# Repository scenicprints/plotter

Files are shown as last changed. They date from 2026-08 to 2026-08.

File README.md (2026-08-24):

# Plotter

A Creality CR-6 SE converted into a pen plotter, plus the Windows app that
drives it. Both halves of the project live here.

Read **[HANDOFF.md](HANDOFF.md)** first. It carries the machine's hard rules
(the Z rule, the three sends, the gotchas that cost real time) and the current
tuned values.

## Layout

| Path | What |
|---|---|
| `app/` | **Plotter** — the Windows control app. Electron, one portable `.exe`, no Python, no vpype. Talks to plain Klipper + Moonraker, so it works against any Klipper plotter. See [app/README.md](app/README.md). |
| `machine/` | The machine side. `printer.cfg`, `macros.cfg`, the toolhead holder, firmware, the Pi-side tool scripts, and plotted art. |
| `docs/` | The original phase-by-phase build guide, and the early UI concept the app grew out of. |

### `machine/`

| Path | What |
|---|---|
| `printer.cfg`, `macros.cfg` | Klipper config. `macros.cfg` holds `_PLOT_VARS`, `PEN_UP` / `PEN_DOWN`, `PLOT_ZERO_HERE`, `PLOT_END`. |
| `holder.scad`, `stl/` | The owner-built pen toolhead. LM8UU bearings on 8 mm rods, gravity loaded, no spring. Pen force is carriage mass. |
| `firmware/plot001.bin` | Klipper build for the Creality v4.5.2 board. STM32F103, 28 KiB bootloader, USART1. |
| `tools/` | The earlier Pi-side pipeline: `plot`, `genart`, `mkpulsar`, `mkcard`, `mkcalib`, built on vpype. The app replaced these for day to day use. They still work and are untouched. |
| `art/`, `renders/` | Plotted SVGs and their previews. |
| `NOTES.md` | Build-time hardware notes, pin map, Klipper build target. |

## The machine

- Creality CR-6 SE, v4.5.2 board flashed with Klipper. Stock touchscreen is dead
  by design.
- Pi 4 at `plotter.local` runs Klipper, Moonraker on 7125, Mainsail on 80.
- Toolhead is owner-built and gravity loaded. To change line weight, add or
  remove mass. Never drive Z lower.
- **Z0 is the writing height and the absolute floor.** `position_min: 0`, and
  there is no Z endstop. The reference is set by hand every session and lives
  only in motion state, so a restart wipes it.

## The app

Three sends, in order, each its own card carrying only its own controls:

1. **Writing height** — Z jog, pen up/down, one click locks Z0.
2. **Card position** — XY jog pad, Z jog, card size, one click sets the origin.
3. **Plot** — pick an SVG or a line drawing, add a message, preview, send.

Everything runs in-process: SVG parsing, curve flattening, transforms,
linemerge, linesort, reloop, simplify, filter, layout, gcode. It also traces
PNG and JPG line art itself, splitting ink by thickness so thin strokes get
their centreline and solid shapes get an outline plus a hatch.

### Building it

    cd app
    npm install
    npm test
    npm run dist        # -> app/dist/Plotter.exe

`app/dist/` and `app/node_modules/` are not tracked.

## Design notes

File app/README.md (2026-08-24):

# Plotter

Windows control app for the CR-6 SE pen plotter. One portable `.exe`, no Python,
no vpype, no dependencies on the machine side. It talks to plain Klipper +
Moonraker, so it works against any Klipper plotter, not just this one.

    dist\Plotter.exe

## What it does

The three sends, in order, each as its own card carrying only its own controls:

1. **Writing height** — Z jog, pen up/down, then one click locks Z0.
2. **Card position** — XY jog pad, Z jog, card size, one click sets the origin.
3. **Plot** — pick an SVG or a line drawing, add a message, preview it, send it.

Plus jog, homing, pen test, live progress, pause, cancel, emergency stop, a
machine console, and a preview showing draw versus travel with a time estimate.

### Setting the origin

**Pen is at** takes any of the four corners or **the centre**. Corner mode adds
half the measured size to reach the sheet centre; centre mode reads the origin
straight off the pen and the measured size only records the sheet dimensions,
so it carries no sighting error at all.

Both modes need Z, because placing the pen accurately means lowering it until
it nearly touches. Step 2 therefore carries its own Z jog with its own step,
separate from step 1's fine steps.

Homing clears the gcode offset but leaves the paper size behind. The app treats
an origin of exactly 0,0 as "not set", because the sheet centre can never
legitimately be the machine origin. Without that, step 2 showed a green tick
over an origin that was gone.

## Drawings, not just SVGs

Drop a PNG or JPEG of line art and it is traced to paths on the spot. Electron
decodes the image itself, so this adds no dependency. The trace controls only
appear for a raster; an SVG never sees them.

Two treatments, picked per pixel by how thick the ink is:

- **Thin strokes get their centreline.** The skeleton of a 2px line is the
  line, so the pen draws it once instead of once down each side.
- **Solid shapes get an outline and a hatch.** Thinning a filled shape does
  not give you its middle, it gives you a ragged spine with spurs. Eyebrows,
  eyelashes, pupils and lips all fail that way, and a face traced without
  this has scribbles where its eyes should be.

**Fill over mm** is the line between the two, in millimetres of finished plot.
Anything inked thicker than that is a shape; anything thinner is a line. A blob
is only promoted if its *core* survives erosion, because a line that merely
thickens for a few pixels grows into a respectable-looking blob and would
otherwise plot as a stray black dash.

Three more things that matter:

- **Tolerances are in millimetres of paper**, converted against the image's own
  resolution, so re-exporting the same drawing at a different size does not
  change the result.
- **The image is upsampled 2x before thinning.** A 2px line has nowhere to put
  a middle; at 4px the skeleton lands where it should.
- **Smoothing happens against the pixel grid, inside the tracer.** A skeleton
  follows whole pixels, so a gently sloping line arrives as a staircase. The
  Simplify setting is in mm and is meant for real curves in real SVGs; at
  raster scale it is far too fine to flatten that, so the tracer does it.

**Save traced SVG** writes the drawing out as reusable artwork, cleaned with
the same tolerances the plot used.

**Blank an area** drags a rectangle over the preview and erases that part of
the image before tracing. It exists for artwork with lettering already rendered
into it: see below for why that has to go.

## Writing on it

Type a message and it is drawn in a **single-stroke font**, where each letter is
the path the pen travels rather than an outline to be filled. A normal font's
`o` is two closed curves, so a pen draws a hollow ring and at card sizes the
two sides of a stem smear together. These draw one line down the middle.

Eighteen fonts ship with the app in `src/fonts` (Hershey and the EMS set, taken
from Inkscape's Hershey Text extension), so nothing needs installing.

Text works **with artwork or on its own** — a card that is only a message is a
perfectly good plot.

Size is **cap height in millimetres**, measured off the font's own `H` rather
than its metadata, which several of these files get wrong. That means 5 mm
looks the same whichever font you pick.

Text is composed in paper space **after** the artwork is fitted, so 5 mm means
5 mm on the card. Folding it in before the fit would let a scale of 0.87
silently turn it into 4.35 mm, and the point of the setting is that you can
measure the result. Position is in millimetres from the sheet centre.

**If the artwork already has type in it, blank it out first.** Rendered type
traces into broken letters: thinning a filled letterform eats the dots on the
i's and the descenders on the y's, and you get "Happ, 6th Birthda,!". There is
no fixing that in the trace, because the input is an outline and the tracer is
looking for a skeleton. Erase it and set the words again.

Tracing a big drawing takes a second or two, so the result is cached against
everything that actually changes it. Feeds and dry run do not re-trace.

## The SVG pipeline is in-process

`src/core/` reimplements what `plot` + vpype did on the Pi:

| File | Does |
|---|---|
| `xml.js` | minimal XML reader |
| `svgpath.js` | path `d` parser, all commands, adaptive curve flattening, arcs |
| `svgdoc.js` | shapes, transforms, units, viewBox, layers -> polylines in mm |
| `trace.js` | raster -> paths: threshold, fill split, thinning, hatch |
| `strokefont.js` | SVG stroke fonts -> typeset paths in mm |
| `geom.js` | simplify, merge, spatial-grid nearest neighbour, sort, reloop |
| `pipeline.js` | fit, auto-rotate, order, gcode, time estimate |

A trace enters `pipeline.buildLayers` as one layer of polylines rather than
being serialised to SVG and parsed straight back. It arrives as raw skeleton
fragments — fifty thousand of them for a portrait — because `simplify`,
`merge` and `filterMin` are already exactly the clean-up a trace needs. That
is also why a trace is a single layer: layers exist for pen changes, and a
traced drawing is one pen's work.

`node test-geom.js` runs 35 correctness tests (circle perimeter, arc flags,
S/T continuation, transform composition, unit conversion, layer order).
`node test-trace.js` runs 40 over the tracer on synthetic rasters (thinning,
erosion, fill detection, scale independence, SVG round trip, huge-input safety).
`node test-text.js` runs 39 over the fonts and typesetting (every glyph present,
o really is one stroke, cap-height sizing, alignment, composition onto a plot).
`node test-core.js` runs the real artwork through end to end.
`node test-live.js` reads the actual machine, read-only.
`node_modules\.bin\electron test-trace-live.js <image>` traces a real file and
prints what the Plot card would show. It needs Electron for image decoding.

Two things that had to be right and are easy to get wrong:

- **Curve tolerance is transformed into each element's own coordinate system.**
  Flattening happens in local user units, so a viewBox scale would otherwise
  multiply the real-world error silently.
- **`<polygon>` is read and kept closed.** vpype writes closed paths as
  `<polygon>` and cannot read them back, which loses closed geometry on any
  round trip. There is no round trip here, and the reader handles it anyway.

## Machine rules it enforces

All of these came from something that actually went wrong:

- Z0 is the writing height **and** the floor. Setting a *new*, lower height
  means releasing the old reference first, so "Unlock Z0 to go lower" does the
  clear and the re-declare in one press rather than leaving a dead button and
  an error that names neither step. Nothing commands Z below it, and
  Klipper's own `position_min: 0` is the backstop. A refused move is explained
  rather than shown as a raw error.
- Positions are read only after `M400`. Straight after `G28` the second homing
  pass is still running and the number is wrong.
- After homing, X/Y park off the plate, so it moves back over the bed itself.
- Preflight before every send: Klipper ready, X/Y homed, Z referenced, Z0 set,
  paper size set, not already printing.
- **The sheet the gcode was laid out for must match the sheet the machine is
  set to**, or the send is refused. This is the error that ruined a card.
- Cancel lifts the pen but never drops the motors, so the Z reference survives.
- The generated gcode does **not** call `PLOT_END`. Loaded copies of that macro
  have run `M84`, which erases the hand-set Z reference, and its park move
  overran the rail. It ends with `PEN_UP` and a plain lift instead.
- Lift and feeds are read live off `_PLOT_VARS` at connect, never hardcoded, so
  the estimate matches the machine rather than a stale config on the laptop.

## Restart recovery

A Klipper restart wipes the origin, the paper size and the Z reference. The app
remembers the last corner and offers it back in a banner. Restoring the corner
is safe on its own: it only sets numbers, and the machine re-homes to the same
physical place. **The writing height still has to be set by hand**, because it
is a physical position with no endstop behind it.

## Dry run

On by default. Traces the whole plot in the air at Z20, clear of the hold-down
magnets, drawing nothing, so placement can be checked before committing ink.
It emits no `PEN_DOWN` at all, which is why it finishes in a fraction of the
time: the cake card is 1m 57s dry against 14m 24s real.

## Time model, and how to actually go faster

Plot time is dominated by pen lifts, not drawing. Each path costs
`lift/z_up_feed + lift/z_down_feed`: almost exactly 1.0 s at the machine's lift
of 10 mm with feeds 1800/900, read live off `_PLOT_VARS` at connect. Note that
the `macros.cfg` checked into `~/plotter` currently says lift 2.0 and 900/600,
which the machine does **not** agree with; the live values are the ones above,
and lift has to clear the carriage compression or the pen never leaves the paper.

**Merge is the lever, and it is a big one.** It joins paths whose ends nearly
touch, and every join removed is a lift saved. Measured on a 1228x1281 traced
portrait:

| Merge mm | Paths | Extra ink | Estimate | vs 0.1 |
|---|---|---|---|---|
| 0.1 | 1977 | +2% | 36m 26s | -- |
| 0.25 | 1332 | +8% | 25m 50s | -29% |
| **0.5** | **1034** | **+10%** | **20m 56s** | **-43%** |
| 1.0 | 548 | +17% | 12m 58s | -64% |
| 2.0 | 248 | +25% | 8m 11s | -78% |

**0.5 is free**: side by side with 0.1 the drawing is indistinguishable, and it
is 43% quicker. Past that you are paying in ink, because merging draws
*through* the gap rather than lifting over it. At 1.0 a stippled beard starts
joining into zigzags; at 2.0 it is a mesh and the teeth are gone. Fine detail
is what breaks first, so a portrait wants 0.5 where a bold line drawing will
happily take 2.

Raising **Min path** helps far less: it only removes ink you wanted.

Ordering is not worth optimising. Travel is around 3 m at 9000 mm/min, some
20 seconds of a twenty-minute plot, so a better tour than greedy
nearest-neighbour would win seconds.

A direction-aware merge, which only joins when the stroke genuinely carries on,
was built and measured and then removed: at matched ink it produced *more*
paths than the plain nearest-first merge, because the free zero-length joins at
skeleton junctions have mismatched directions and the angle test refused them,
reaching for distant collinear ends instead. Plain merge at a lower tolerance
beats it on both axes.

## Development

    npm start          # run from source
    npm test           # geometry + pipeline tests
    npm run dist       # build dist\Plotter.exe

`PLOTTER_SMOKE=1 PLOTTER_SMOKE_OUT=x.png npm start` boots, screenshots and
quits, for checking the UI without leaving a window open.
`PLOTTER_USERDATA=<dir>` points the saved state somewhere disposable.

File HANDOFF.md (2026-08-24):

# CR-6 SE Pen Plotter — Handoff

**The plotter works.** Read this before touching anything.

Original build guide: `docs/cr6se-plotter-build-guide.md`
(phases 0–12). Phases 1–4 and 9 are done. Owner does physical work; you do
software over SSH.

---

## Connecting

- Pi: `plotter.local` or `192.168.1.239`, user `jkevin`, SSH by key from the
  owner's laptop. Passwordless sudo.
- Mainsail: `http://plotter.local` · Moonraker API: port 7125
- Config in git at `~/plotter/` (printer.cfg, macros.cfg, tools/, art/)
- mDNS drops out occasionally — fall back to the IP.

## Hardware

- Creality **v4.5.2** board flashed with Klipper (`~/plotter/firmware/plot001.bin`,
  STM32F103, 28 KiB bootloader, USART1). Stock touchscreen is dead by design.
- Toolhead is **owner-built**: LM8UU bearings on 8 mm smooth rods,
  **gravity loaded — no spring, no rubber band** (both were tried, abandoned).
  Pen force = carriage mass. To change line weight, add or remove mass.
  Never try to increase pressure by driving Z lower — it cannot go lower.
- Carriage float: **15.9 mm** (owner measured 0.6278 in).

---

## THE Z RULE — non-negotiable

**Z0 IS the writing height AND the absolute floor.** `stepper_z position_min: 0`,
so Klipper itself rejects any move below it (verified: `G1 Z-1` returns
"Move out of range"). `PEN_DOWN` goes to Z0 and no further.

There is no Z endstop. The reference is set **by hand** every time and lives
only in motion state.

---

## The workflow — THREE SENDS

The owner confirmed this model and wants it preserved:

1. **Z height** — jog down until the pen writes with the carriage floating,
   then `PLOT_ZERO_HERE`
2. **Corner** — put the pen on the **bottom-left** corner of the card, then set
   the origin from that corner plus the card's measured dimensions
3. **Plot** — generate, upload, start

Steps 1 and 2 need the pen physically positioned, so they cannot be batched.
Step 3 is one action. Once set, further plots are a single action.

### Setting the origin from ONE corner (USE THIS)

Two-corner sighting (`PLOT_P1`/`PLOT_P2`) is still available but **one corner
plus the owner's measured dimensions is better and is what finally worked**:
it removes a whole sighting error and takes the size from a ruler rather than
from two eyeballed points.

With the pen on the bottom-left corner at machine (x, y) and card W x H:

    centre = (x + W/2, y + H/2)
    SET_GCODE_OFFSET X=<cx> Y=<cy>
    SET_GCODE_VARIABLE MACRO=_PLOT_VARS VARIABLE=paper_w VALUE=<W>
    SET_GCODE_VARIABLE MACRO=_PLOT_VARS VARIABLE=paper_h VALUE=<H>

Worked example: corner X23 Y59, card 150x100 -> centre X98 Y109. Perfect plot.

---

## Gotchas that cost real time today

- **Lift must exceed the carriage compression.** At the writing height the
  carriage is pushed up off its stop. If `lift` is smaller than that
  compression the pen never leaves the paper and every travel move draws —
  the output is scribbles. 2 mm was not enough; **10 mm works**. Default is
  now 10 in macros.cfg.
- **A restart wipes homing AND the Z reference AND the origin AND paper size.**
  Everything except what is in the config files. After any restart: re-home,
  re-set the corner, re-set Z.
- **Never restart Klipper while the machine is in a hand-set state.** Prefer
  `SET_GCODE_VARIABLE` over config edits mid-session. This ruined the owner's
  setup more than once.
- **`idle_timeout` used to run M84 after 10 min**, silently destroying the Z
  reference. Fixed: `timeout: 86400` and a gcode that does NOT drop motors.
- **`PLOT_END` used to call M84** — same problem after every finished plot.
  Removed. Its park move also overran the rail because it ignored the active
  gcode offset; now offset-aware.
- **Pen macros must check `"z" in printer.toolhead.homed_axes`**, not just an
  internal flag. A flag alone once said "zeroed" while Klipper had unhomed,
  and a job started and slammed the carriage into the bed.
- **Don't read a position immediately after `G28`.** The second homing pass is
  still running and you will read a wrong number. Cost two false alarms.
- **After homing, X/Y park at -5,-2 which is OFF the plate.** Move back over
  the bed before doing anything.
- **vpype writes closed paths as `<polygon>` and cannot read `<polygon>` back.**
  Any round-trip through an intermediate SVG silently loses closed geometry.
  Do all processing in ONE pipeline.
- **vpype `layout` enforces portrait** unless `--landscape` is passed. Without
  it a landscape sheet is laid out portrait and the centring is off by half
  the difference.
- **Writing tool files from Windows introduces CRLF** and breaks the shebang.
  Always normalise to LF before scp.
- **SVG layers are drawn in order** (layer 1, then layer 2). The owner's card
  art has `art` and `text` layers, so the text plots last. A late position
  error therefore looks like "only the text moved".

## UNRESOLVED

One card was ruined: the text landed on top of the cake. Suspected skipped
steps from `max_accel` 500 -> 2500, and the acceleration was reverted — **but
the final perfect card also ran at 2500**, so acceleration is probably NOT the
cause. The more likely explanation is an origin/corner error, since that
attempt used two-corner sighting and the successful one used the single-corner
method. Treat as unexplained. If it recurs, drop `max_accel` to 500 first.

**Z at 30 mm/s is proven, not open.** The perfect card ran 529 pen lifts, every
one at `z_up_feed` 1800 = 30 mm/s. Skipped steps would have drifted the writing
height over 529 cycles and the line would have faded out or dug in partway
through. It did not. That is a far more demanding test than a 25-cycle macro.

`ZSPEEDTEST N=25` is loaded and has never been run. It is now only worth
running if the speed is pushed **above** 30.

---

## Current tuned values

| Setting | Value | Notes |
|---|---|---|
| `max_accel` | 2500 | raised from 500; produced a perfect plot |
| `square_corner_velocity` | 8 | |
| `max_z_velocity` | 30 | raised from 15; proven over 529 lifts on the good card |
| `lift` | 10 mm | must exceed carriage compression |
| | | **`macros.cfg` in this repo says 2.0 and is STALE** — the machine reports 10 |
| `z_up_feed` / `z_down_feed` | 1800 / 900 | down is slower on purpose: no spring to absorb landing |
| `idle_timeout` | 86400 | must never drop motors |

**Plot time is dominated by pen lifts, not drawing.** At lift 10 mm each path
costs ~1.0 s. A 527-path drawing is ~8m47s of lifting and under a minute of
drawing. To speed up: fewer paths (`--filter-min`), or a smaller lift.

---

## Tools on the Pi (`machine/tools/` here, `~/plotter/tools/` on the Pi, all on PATH)

- **`plot`** — SVG to plotted. Layout, optimise, filter, gcode, preview,
  time estimate, upload. Origin is the paper CENTRE. Dry run is the default
  and flies at Z20 to clear magnets. Key flags: `--size WxH`, `-m` margin,
  `--pen`, `--filter-min`, `--dry-z`, `--keep-layers`, `--go`.
- **`genart`** — flow / spiral / moire / lissajous generative art.
- **`mkpulsar`** — ridgeline plot with hidden-line removal.
- **`mkcard`** — greeting card, auto-sized Hershey text plus a cake.
- **`mkcalib`** — Phase 10 calibration sheet.

vpype 1.15 with gwrite, hatched, vectrace, flow_img. Hershey `text` is built
into vpype core — no plugin needed.

**SVG artwork must be line art**: stroked paths, `fill="none"`. A filled SVG
plots as the OUTLINE of the filled regions (coloring-book look) and produces
hundreds of tiny contours, each costing a pen lift.

Raster artwork is a different matter: since 2026-08-23 the app traces PNG/JPG
itself and handles solid shapes deliberately, so this restriction does not
apply to images. See below.

---

## The Windows app is BUILT

`app/dist/Plotter.exe` - one portable file, 89 MB,
no install, no Python. Source and full notes in `app/README.md`.
Electron, matching MZ Forge and Anvil.

It replaces `plot` + vpype entirely for day to day use. The Pi stays plain
Klipper + Moonraker; the app does SVG parsing, curve flattening, transforms,
linemerge, linesort, reloop, simplify, filter, layout and gcode in-process.
The Pi tools still work and are untouched.

The three sends are the UI: three cards, each carrying only its own controls
(Z jog inside step 1, the XY pad inside step 2). Dry run is ON by default.

### It traces drawings too (2026-08-23)

Drop a PNG or JPG of line art in step 3 and it becomes paths in-process. No
Inkscape, no potrace, no autotrace: Electron decodes the image itself.

Ink is split by thickness and the two halves are treated differently:

- **Thin strokes get their centreline**, so the pen draws each line once
  instead of once down each side.
- **Solid shapes get an outline plus a hatch.** Thinning a filled shape does
  not give its middle, it gives a spiky spine. Eyebrows, eyelashes, pupils and
  lips all fail that way, and a face traced without this has scribbles for
  eyes. "Fill over mm" is the dividing line.

Everything lands on **one layer** — layers are for pen changes and a traced
drawing is one pen's work. "Save traced SVG" writes it out as reusable artwork.

### And it writes (2026-08-23)

Type a message and it is drawn in a **single-stroke font**: each letter is the
path the pen travels, not an outline. Plotting a normal font draws hollow
balloon letters. Eighteen fonts ship inside the app, nothing to install.

Size is cap height in mm, and text is composed AFTER the artwork is fitted, so
5 mm means 5 mm on the card whatever the art was scaled by. Works with artwork
or alone.

**If the artwork already has type rendered into it, blank that area first**
("Blank an area", drag on the preview). Rendered type traces into broken
letters and no setting fixes it.

### Going faster

Pen lifts dominate, ~1.0 s each at the live lift 10 / feeds 1800/900.
**Merge mm is the lever.** Measured on a traced portrait: 0.1 mm gives 1977
paths / 36m 26s, 0.5 gives 1034 / 20m 56s, 1.0 gives 548 / 12m 58s, 2.0 gives
248 / 8m 11s.

**0.5 is free** — indistinguishable from 0.1 by eye, and 43% quicker. Beyond
that merging draws THROUGH gaps: at 1.0 a stippled beard joins into zigzags, at
2.0 the teeth are gone. Fine detail breaks first, so a portrait wants 0.5 and a
bold line drawing will take 2. Travel ordering is not worth touching; it is
~20 s of a twenty-minute plot.

Verified against the live machine on 2026-08-23: read-only status parse,
35 geometry, 40 tracer and 39 text tests, the cake card end to end (747 paths,
14m 24s real / 1m 57s dry), a 1228x1281 wedding portrait traced to 1995 strokes
and 10.29 m of draw in about a second, and the packaged .exe booting,
connecting and tracing.

### What it refuses to do, and why

- Send when the sheet the gcode was laid out for does not match the sheet the
  machine is set to. **This is the error that ruined the card.**
- Send at all unless preflight passes: Klipper ready, X/Y homed, Z referenced,
  Z0 set, paper size set, nothing already printing.
- Drop the motors on cancel. It lifts the pen and leaves them on, so the Z
  reference survives.
- Call `PLOT_END`. Loaded copies of that macro have run `M84`. It emits
  `PEN_UP` + a plain lift instead, the same known-good ending `plotter.toml`
  uses.

### Still by hand

The writing height. It is a physical position with no endstop, so after a
restart the app can restore the corner and the card size from memory but the
Z reference has to be re-set by jogging. The app says so in the banner.

### Note on the local config copies

`macros.cfg` in this folder is STALE against the Pi: it still says lift 2.0,
feeds 900/600, and a `PLOT_END` that calls `M84`. The live machine has lift 10
and feeds 1800/900. The app reads `_PLOT_VARS` off the machine at connect
rather than trusting any local file. Worth pulling the Pi's copy back down
into this repo.

## ALSO PLANNED: hotspot fallback

The owner wants to take the Pi and plotter to places where devices cannot see
each other and IPs change (e.g. work). Plan: NetworkManager AP profile with
lower autoconnect priority than the home network, so it joins `coronawireless`
at home and otherwise broadcasts its own network at a fixed address.

**This is the change most likely to lose SSH access to the Pi.** Do it with a
revert timer, and not while a plot is running.

Also worth doing: a DHCP reservation for the Pi on the owner's UDM Pro.

---

## Working with this owner

- He is hands-on and fast. Give the value, not the reasoning.
- **Never start a plot unless he has clearly asked for it in that moment.**
  Starting one on an assumption wasted a real card and his time.
- Ask before physical actions that could damage something, but do not stack up
  questions — he gets frustrated with repeated confirmation.
- When he corrects you, fix it and move on. Do not explain at length, and do
  not shift blame onto him — his corners were right when I suggested otherwise.
- Verify with a command rather than assuming; several bugs today were only
  caught by actually running the thing.

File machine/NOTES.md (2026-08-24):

# CR-6 SE Pen Plotter - staging repo

Files here are staged on the Windows laptop and copied to the Pi (`~/plotter/`)
once it is reachable. Guide: `docs/cr6se-plotter-build-guide.md`

## Hardware facts established

- Mainboard: **Creality v4.5.2**
- Klipper build target (from upstream `config/printer-creality-cr6se-2020.cfg`):
  - STM32F103
  - **28 KiB bootloader**
  - Communication: **serial on USART1 (PA10/PA9)**, reached over the board's USB
- Pi 4, hostname `plotter`, user `jkevin`

## Pin map, stock -> plotter

| Pin  | Stock use | Plotter use |
|---|---|---|
| PA4  | strain gauge probe | unused (Option C Z-homing if ever wanted) |
| PA6  | case LED output | **servo signal candidate** |
| PA7  | filament switch in | **Z endstop candidate** (Option A) |
| PA0/PA1/PA2 | fans, hotend, bed | deleted from config |

Both PA6 and PA7 are freed by the strip, so Option A (mechanical Z switch)
and a mainboard-timed servo can coexist. Confirm physically at Phase 1.1/6.2.

## Status

- [x] Phase 1 - board identified, build target derived
- [~] Phase 2 - Pi imaged; **not yet on the network** (see below)
- [ ] Phase 3 - firmware build + flash
- [ ] Phase 4 - motion config

## Open problem: Pi will not join WiFi

The Pi boots correctly (rootfs auto-expanded 2.6 GB -> 59 GB, which only
happens on a successful boot) but ignored two headless-config formats:

1. `rpi-preseed.toml` - written per rpi-imager docs for Trixie. Ignored.
2. cloud-init `user-data` / `network-config` - files present on the image but
   apparently not processed. Ignored (no `runcmd` side effects appeared).

Current attempt: the `systemd.run=` + `firstrun.sh` mechanism taken from
rpi-imager's own source (`src/downloadthread.cpp`), which is independent of
whichever config package the image ships. It writes `/boot/firmware/firstrun.log`
and installs `plotter-diag.service` to dump full network state to
`/boot/firmware/diag/net.txt` on the following boot.

**Next diagnostic step:** read `firstrun.log` off the card. Its presence or
absence is decisive - absent means `systemd.run` never fired, present means the
script ran and the log says exactly how far it got.

Fallback if WiFi keeps failing: wired ethernet to the Pi. The configs already
accept DHCP on eth0.

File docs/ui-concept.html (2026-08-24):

Plotter 1.0

plotter.local · Ready

X 98.0 Y 109.0 Z 0.00

–▢✕

Plot Artwork Machine Settings STOP

Klipper restartedLast session: Z0 · corner X23.0 Y59.0 · card 150 × 100

Restore

✓Writing height Z0 locked

Jog down until the pen writes with the carriage floating off its stop, then lock. Z0 is the floor, it cannot go lower.

Z position4.35

Carriage float15.9

▲ +1▲ +0.1

▼ −0.1▼ −1

Step (mm)

0.05 0.1 0.5 1

Pen downPen up

Lock Z0 here

2Card corner bottom-left

Put the pen on the bottom-left corner of the card, enter the size you measured, and set the origin.

X23.0

Y59.0

Centre98 · 109

Step (mm)

0.1 1 10 50

Card preset

150×100 A6 A5 4×6″

Width mm

×

Height mm

Set origin from this corner

3Plot 9m 14s

art-cake-outline.svg

527 paths · drop a new SVG or click to browse

Margin mm

Min path mm

Pen

Dry runFlies at Z20 to clear the magnets, nothing is drawn Send plot

Preview

Draw

Travel

Fit

Paths527

Draw4.24 m

Travel2.91 m

Pen lifts527

Estimate9m 14s

Plotting34% path 179 / 527 · 6m 02s left

Pause Cancel

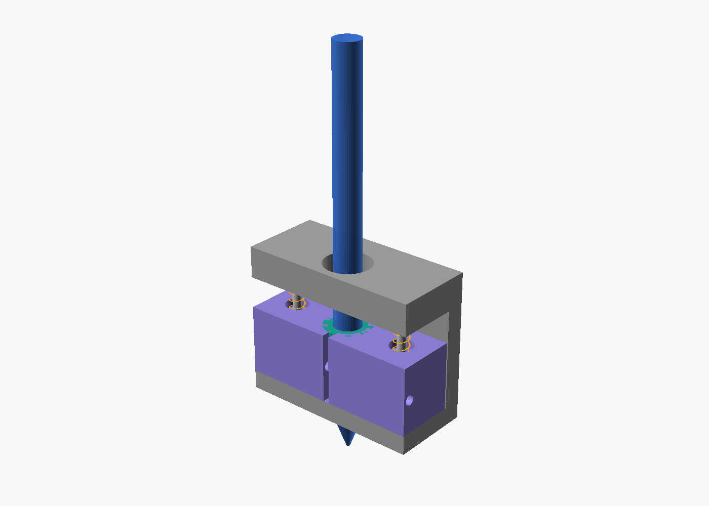
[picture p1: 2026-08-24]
machine/renders/holder-iso.png

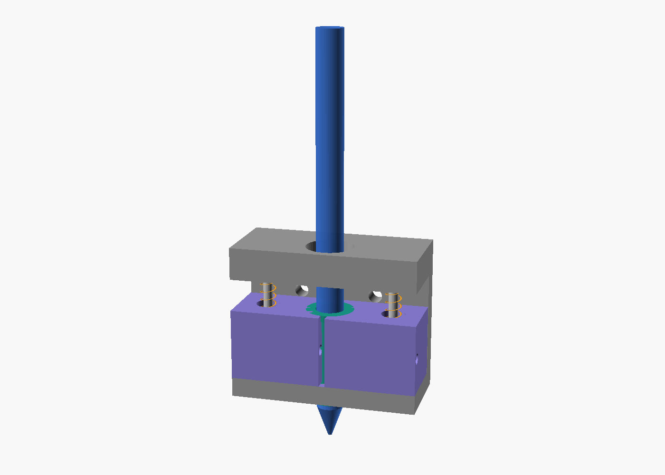
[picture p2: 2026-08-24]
machine/renders/holder-front.png

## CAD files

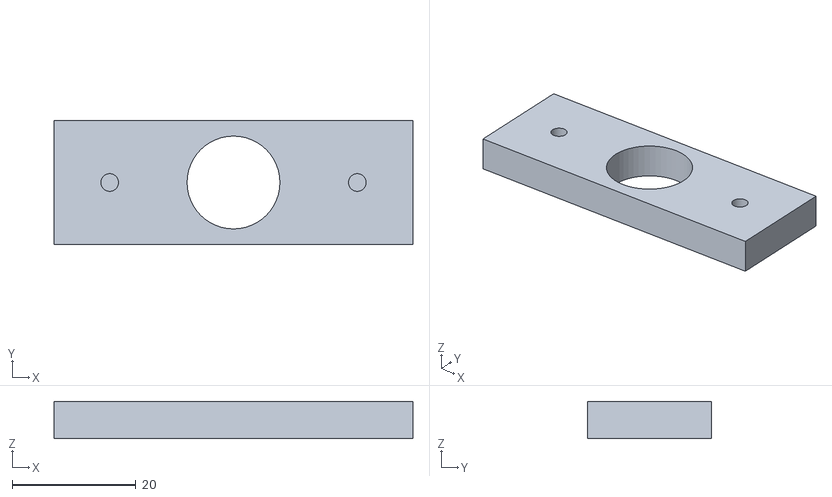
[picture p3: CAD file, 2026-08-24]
machine/stl/holder-bottom.stl
58.0 x 20.0 x 6.00

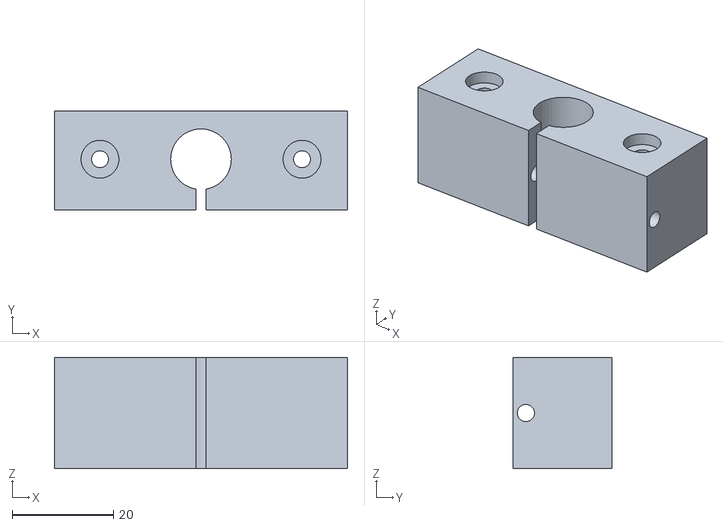
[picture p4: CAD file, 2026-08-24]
machine/stl/holder-carriage.stl
58.0 x 19.5 x 22.0

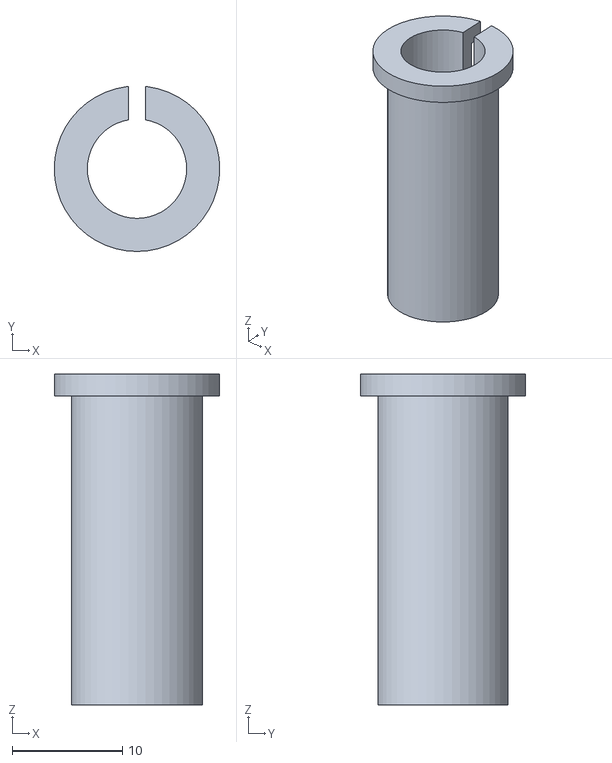
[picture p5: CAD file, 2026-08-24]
machine/stl/holder-sleeve.stl
15.0 x 15.0 x 30.0

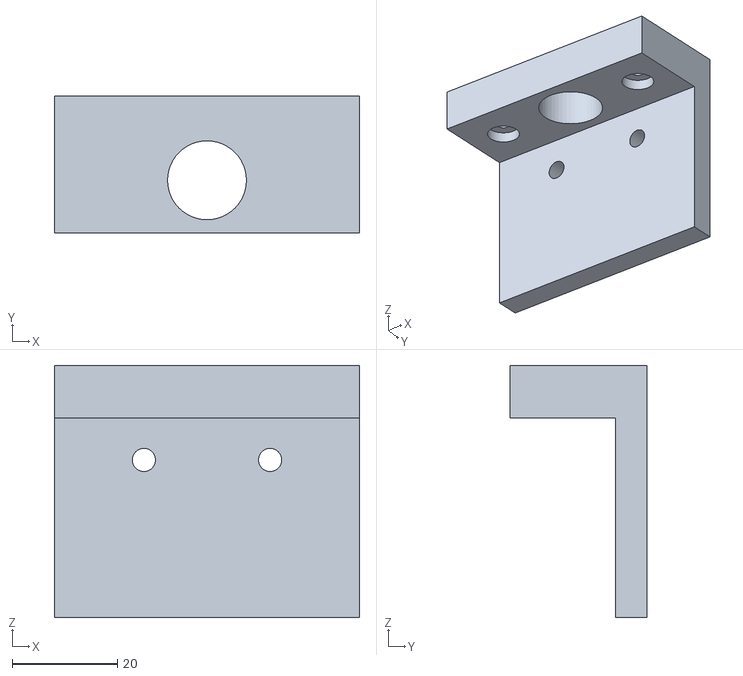
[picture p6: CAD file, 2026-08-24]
machine/stl/holder-top.stl
58.0 x 26.0 x 48.0

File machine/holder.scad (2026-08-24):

// CR-6 SE pen plotter holder, v1
// Two 3mm steel guide rods, sprung carriage, per-pen sleeves.
// Mount-plate hole spacing is a PLACEHOLDER until the bracket is measured.
// All dims in mm.

$fn = 48;

// ---------------- parameters ----------------
rod_d          = 3.0;    // steel rod diameter
rod_len        = 45;     // rod length
rod_spacing    = 40;     // centre-to-centre
rod_clear      = 0.35;   // carriage bore clearance over rod
rod_press      = 0.15;   // press-fit undersize in plates

plate_w        = 58;     // x
plate_d        = 20;     // y
top_t          = 10;     // top plate thickness
bot_t          = 6;      // bottom plate thickness

carriage_h     = 22;
sleeve_bore    = 12;     // carriage centre bore, all sleeves share this OD
pen_hole       = 15;     // pen clearance through both plates

spring_od      = 5.2;    // click-pen spring
spring_wire    = 0.45;
spring_seat_d  = 7.5;    // locating counterbore
spring_seat_dp = 2.5;

wall_t         = 6;      // back wall that meets the bracket
wall_h         = 48;
mount_hole_d   = 4.4;    // M4 clearance  (PLACEHOLDER)
mount_spacing  = 24;     // hole spacing  (PLACEHOLDER - measure bracket)
mount_z        = 30;     // hole height   (PLACEHOLDER - measure bracket)

clamp_slit     = 2.0;
clamp_hole_d   = 3.4;    // M3 clearance

// BIC Cristal sleeve
bic_barrel     = 9.0;    // hex barrel across corners ~8.9
sleeve_len     = 30;
flange_d       = 15;
flange_t       = 2;

// derived
rx = rod_spacing/2;
carriage_z0 = bot_t;                 // carriage rests on bottom plate
top_z0 = rod_len + 1 - 8 + 0;        // top plate underside so rods socket 8mm
// keep simple: place explicitly
top_bottom = 38;                     // underside of top plate
travel = top_bottom - (carriage_z0 + carriage_h);   // = 10mm free travel

// ---------------- parts ----------------

module rod() color("silver") cylinder(d=rod_d, h=rod_len);

module spring(h) {
    color([0.95, 0.62, 0.12])
    linear_extrude(height=h, twist=-360*6, slices=120)
        translate([spring_od/2 - spring_wire/2, 0]) circle(d=spring_wire);
}

module bottom_plate() color([0.62,0.62,0.62]) difference() {
    translate([-plate_w/2, -plate_d/2, 0]) cube([plate_w, plate_d, bot_t]);
    // rod sockets (blind, press fit)
    for (s=[-1,1]) translate([s*rx, 0, 1]) cylinder(d=rod_d-rod_press, h=bot_t);
    // pen clearance
    cylinder(d=pen_hole, h=3*bot_t, center=true);
}

module top_plate() color([0.62,0.62,0.62]) difference() {
    union() {
        translate([-plate_w/2, -plate_d/2, top_bottom]) cube([plate_w, plate_d, top_t]);
        // back wall down to bottom, meets the bracket face
        translate([-plate_w/2, plate_d/2, 0]) cube([plate_w, wall_t, wall_h]);
    }
    // rod sockets, blind from below
    for (s=[-1,1]) translate([s*rx, 0, top_bottom]) cylinder(d=rod_d-rod_press, h=8);
    // pen clearance
    translate([0,0,top_bottom-1]) cylinder(d=pen_hole, h=top_t+2);
    // spring locating counterbores on the underside
    for (s=[-1,1]) translate([s*rx, 0, top_bottom-0.01]) cylinder(d=spring_seat_d, h=spring_seat_dp);
    // bracket mount holes (PLACEHOLDER spacing)
    for (s=[-1,1]) translate([s*mount_spacing/2, plate_d/2-1, mount_z])
        rotate([-90,0,0]) cylinder(d=mount_hole_d, h=wall_t+2);
}

module carriage() color([0.55,0.50,0.85]) difference() {
    translate([-plate_w/2, -plate_d/2, carriage_z0]) cube([plate_w, plate_d-0.5, carriage_h]);
    // rod bores
    for (s=[-1,1]) translate([s*rx, 0, carriage_z0-1]) cylinder(d=rod_d+rod_clear, h=carriage_h+2);
    // spring seats on top face
    for (s=[-1,1]) translate([s*rx, 0, carriage_z0+carriage_h-spring_seat_dp]) cylinder(d=spring_seat_d, h=spring_seat_dp+1);
    // sleeve bore
    translate([0,0,carriage_z0-1]) cylinder(d=sleeve_bore, h=carriage_h+2);
    // clamp slit, front face to bore
    translate([-clamp_slit/2, -plate_d/2-1, carriage_z0-1]) cube([clamp_slit, plate_d/2+1, carriage_h+2]);
    // M3 clamp screw crossing the slit
    translate([-plate_w/2-1, -7.5, carriage_z0+carriage_h/2]) rotate([0,90,0]) cylinder(d=clamp_hole_d, h=plate_w+2);
}

module sleeve() color([0.10,0.62,0.55]) difference() {
    union() {
        cylinder(d=sleeve_bore-0.15, h=sleeve_len);
        translate([0,0,sleeve_len-flange_t]) cylinder(d=flange_d, h=flange_t);
    }
    translate([0,0,-1]) cylinder(d=bic_barrel, h=sleeve_len+2);
    translate([-0.75, 0, -1]) cube([1.5, flange_d, sleeve_len+2]);
}

module pen_mock() color([0.22,0.45,0.85,0.85]) {
    translate([0,0,-4]) cylinder(d=8.5, h=118);
    translate([0,0,-14]) cylinder(d1=1.2, d2=8.5, h=10);
}

// ---------------- assembly ----------------
module assembly() {
    bottom_plate();
    top_plate();
    for (s=[-1,1]) translate([s*rx, 0, 1]) rod();
    carriage();
    // springs sit between carriage top and top plate underside
    for (s=[-1,1]) translate([s*rx, 0, carriage_z0+carriage_h-spring_seat_dp]) spring(top_bottom - (carriage_z0+carriage_h) + 2*spring_seat_dp);
    // sleeve in carriage, flange resting on carriage top
    translate([0,0,carriage_z0+carriage_h-sleeve_len]) sleeve();
    pen_mock();
}

part = "assembly"; // assembly | top | bottom | carriage | sleeve

if (part == "assembly") assembly();
if (part == "top")      top_plate();
if (part == "bottom")   bottom_plate();
if (part == "carriage") carriage();
if (part == "sleeve")   sleeve();

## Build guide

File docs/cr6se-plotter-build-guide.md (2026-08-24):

# CR-6 SE → Pen Plotter: Full Build Guide

A step-by-step conversion of a Creality CR-6 SE into a dedicated pen plotter running
Klipper on a Raspberry Pi. This machine will never 3D print again — that assumption
drives many of the decisions below.

**This document is written for two readers:**

- **[HUMAN]** — physical work, judgement calls, anything involving a screwdriver or eyeballs.
- **[CC]** — Claude Code, working over SSH on the Pi. Software, config, scripts, debugging.

Each phase ends with a **Done when** line. Do not move to the next phase until it's true.

---

## A note on ordering

The usual version of this build has a hard constraint: print your plastic parts before you
remove the hotend, because afterwards the machine can't make its own parts.

**That constraint does not apply here.** There are other printers available, so the pen
holder is not a one-shot design you have to get right before committing. It's an iterative
fit-and-refine loop that can run *while the CR-6 is already stripped and on the bench* —
which is strictly better, because you can measure the real bracket, test the real flex, and
reprint the same afternoon.

Phase 0 is therefore just measuring and shopping. The holder design gets its own phase
(Phase 6), positioned after the strip where it belongs.

---

## Verification policy for [CC]

Some details in this guide are version-sensitive and may have drifted. Before acting on
anything marked **[VERIFY]**, fetch current upstream documentation and reconcile. If
upstream contradicts this document, upstream wins — say so out loud rather than silently
following either one.

Primary sources:
- Klipper install & config: https://www.klipper3d.org/
- Klipper example configs: `klipper/config/` in the cloned repo
- KIAUH: https://github.com/dw-0/kiauh
- vpype: https://vpype.readthedocs.io/

---

# PHASE 0 — Print parts and buy things

## 0.1 [HUMAN] Print the parts that aren't design-sensitive

These don't interact with the toolhead, so there's nothing to iterate on. Print whenever.

| Part | Notes |
|---|---|
| Paper registration corners | L-shaped blocks, print 2–4 |
| Pi case or bed-frame mount | Optional, keeps wiring tidy |
| Cable strain relief | For the slimmed-down toolhead loom |

The pen holder and servo mount are **not** on this list. They depend on measurements you
can't take until the toolhead is bare. See Phase 6.

## 0.2 [HUMAN] Set aside a design printer

Pick whichever of the other machines has the best small-part accuracy and keep it loaded
with a filament you like. Phase 6 will ask it for four or five iterations over a day or
two, and you don't want that competing with a long print.

PETG is the better choice over PLA here — the holder sits under constant light spring
load, and PLA creeps under sustained stress over months.

## 0.3 [HUMAN] Shopping list

**Electronics**
- Raspberry Pi (any Pi 3B+ or newer; Pi Zero 2 W works but is slow to build firmware on)
- Good 5V power supply for the Pi — undervoltage causes bizarre, hard-to-diagnose faults
- microSD card for the Pi, 16 GB+
- **A second microSD card, 8 GB or smaller, for flashing the mainboard** (see 3.3)
- SG90 or MG90S 9g servo (MG90S has metal gears and is worth the extra dollar)
- Dupont jumper wires, female-to-female
- USB-A to USB-B cable (Pi → printer mainboard) — probably already have one
- *Optional:* mechanical microswitch for a Z endstop (see 4.4)

**Pens — buy in this order**

| Priority | Pen | Why |
|---|---|---|
| **Buy first** | **BIC Cristal ballpoint, box of 10** | Your calibration pen. Nearly indestructible, tolerates crashes and bad Z, costs nothing. Do all setup and testing with these. Never risk a good pen on an untuned machine. |
| **Buy first** | **Sakura Pigma Micron 05 (0.45 mm)** | The default "good" plotter pen. Pigment ink, archival, consistent line, doesn't bleed. The 05 is the sweet spot — finer tips (01, 005) fray faster and need slower speeds. |
| Add soon | **Sharpie Fine Point** | Dark, bold, cheap, bulletproof. Bleeds on cheap paper. Great for large generative work. |
| Add soon | **Uni-ball Signo / Sakura Gelly Roll, white** | For plotting on black paper, which looks fantastic and is half the reason people build these. |
| Technical work | **Staedtler Pigment Liner 308** or **Rotring Tikky Graphic** | Consistent widths in a matched set (0.1 / 0.3 / 0.5), good for drawings where line weight is semantic. |
| Later, if you get serious | **Rotring Isograph** (refillable) | Best line consistency available. Expensive, clogs if left uncapped or unused, needs actual maintenance. Not a starter pen. |

**Do not start with fineliners finer than 0.3 mm.** They fray on any paper that isn't
very smooth, and they punish Z errors that a ballpoint would shrug off.

**Paper**
- **Bristol board, smooth (not vellum) surface** — the plotter standard. Rough paper
  destroys fineliner tips.
- HP Premium32 or similar heavy smooth laser paper for cheap testing
- Black cardstock if you bought white gel pens

**Hold-down**
- Low-tack masking tape or small bulldog clips
- The printed registration corners from 0.1

**Done when:** registration corners printed, pens and paper ordered, Pi in hand, a design
printer standing by.

---

# PHASE 1 — Identify your mainboard

**Do this before downloading anything.** The CR-6 SE shipped with several different
boards across production runs, and flashing the wrong firmware is the one genuinely
risky step in this build.

## 1.1 [HUMAN] Open the base and read the silkscreen

Power off, unplug from mains, remove the bottom cover. Photograph the board. Look for:

- A version string silkscreened on the PCB (e.g. `CR-6 SE v4.5.2`, `v4.5.3`, `ERA`)
- The main MCU chip marking — read the text on the largest square chip. You're looking
  for something like `STM32F103RET6` or `GD32F303RET6`.
- Whether there are any **unused 3-pin headers** (5V / GND / signal). Photograph these
  and any labels near them. You may want one for the servo and one for a Z endstop.

Write down exactly what you see. Guessing here is how boards get bricked.

## 1.2 [CC] Determine the correct Klipper build target

**[VERIFY]** Given the board revision and MCU marking from 1.1, determine:
- Klipper `menuconfig` MCU family
- Correct **bootloader offset** (Creality 32-bit boards commonly use 28 KiB, but confirm
  for this specific revision)
- Communication interface (USB vs serial, and which pins)

Note for [CC]: some CR-6 SE boards use a **GD32F303**, which is a clone of the STM32F103.
Klipper handles this, but the correct target selection is a known gotcha. Check the
Klipper docs and the `klipper/config/` directory for a shipped CR-6 SE example config
before deciding. If you cannot establish this with confidence, **stop and say so** rather
than producing a firmware binary on a guess.

**Done when:** board revision, MCU part number, and Klipper build target are all written
down and agreed on.

---

# PHASE 2 — Raspberry Pi setup

## 2.1 [HUMAN] Flash and boot the Pi

- Raspberry Pi Imager → Raspberry Pi OS **Lite** (64-bit). No desktop needed.
- In the Imager's settings gear: set hostname (`plotter` is a good choice), enable SSH,
  set username/password, configure WiFi.
- Boot the Pi, confirm you can `ssh` in.

## 2.2 [HUMAN] Hand the Pi to Claude Code

Give [CC] SSH access. From here [CC] does the software work.

## 2.3 [CC] Install the Klipper stack

Use **KIAUH** (Klipper Installation And Update Helper) — it handles the whole stack and
its service wiring correctly.

Install, in order:
1. **Klipper**
2. **Moonraker** (the API layer — this is what lets you drive the machine programmatically)
3. **Mainsail** (web UI — the human will want this for jogging and emergency stop)

**[VERIFY]** KIAUH's repo URL and install procedure.

Set up a git repo at `~/plotter/` to version-control `printer.cfg`, macros, vpype configs,
and scripts. Commit after every working change. You will break things and want to walk back.

**Expect Mainsail to look half-broken** once you're running — empty temperature graphs, no
extruder panel. Nothing is wrong; you deleted those sections from `printer.cfg` on purpose
in Phase 4. The jog controls, console, and file manager are all you need from it. A
plotter-shaped replacement is Phase 12, deferred until you've actually used the machine.

**Done when:** Mainsail loads in a browser, `systemctl status klipper` is running (it will
report an MCU connection error — that's expected, nothing is flashed yet).

---

# PHASE 3 — Build and flash the mainboard firmware

## 3.1 [CC] Build the firmware

In `~/klipper`: run `make menuconfig` with the settings established in 1.2, then `make`.

Output lands at `~/klipper/out/klipper.bin`.

## 3.2 [CC] Prepare the binary

Copy `klipper.bin` to a **uniquely named** file — e.g. `plot001.bin`. Increment this
number on every reflash, forever.

**Why:** Creality bootloaders track the last-flashed filename and will silently skip a
file with a name it has already seen. A "failed flash" that is actually just a skipped
flash has eaten many hours.

## 3.3 [HUMAN] Flash it

- Use the **small (8 GB or under) SD card**, formatted **FAT32, 4096-byte allocation unit
  size**. Large cards and wrong cluster sizes are the #1 cause of Creality boards refusing
  to flash.
- The card should contain **only** the `plot001.bin` file. Nothing else.
- Printer **off**. Insert card. Power **on**. Wait 15–30 seconds. The screen may stay
  blank or show garbage — this is expected and fine.
- Power off, remove the SD card.

## 3.4 [HUMAN] Connect the Pi

USB cable from Pi to the printer mainboard. Power the printer on.

## 3.5 [CC] Find the MCU

Run Klipper's serial ID helper to get the `/dev/serial/by-id/...` path. Record it — it
goes in `printer.cfg`.

If nothing appears: the flash didn't take. Return to 3.2, increment the filename, and
re-check the SD card format before assuming a firmware problem.

**Expect the stock touchscreen to be dead from now on.** It's a separate MCU that doesn't
speak Klipper. This is normal and doesn't matter — you'll drive everything from Mainsail.

**Done when:** `ls /dev/serial/by-id/` shows the board.

---

# PHASE 4 — Minimal motion config

**Goal: get X, Y, and Z moving. Nothing else. Do not attach a pen yet.**

## 4.1 [CC] Write a stripped `printer.cfg`

Start from the CR-6 SE example config if Klipper ships one, then **delete**:
- `[extruder]` — entirely
- `[heater_bed]` — entirely
- `[heater_fan]`, `[fan]` — entirely
- Any `[verify_heater]`, thermistor, or thermal protection sections
- Any probe / bed mesh sections **for now** (added in Phase 7)

This deletion is the whole point of the Klipper path: MINTEMP faults, cold-extrusion
guards, and thermal runaway protection stop being things you work around because they
stop existing.

Keep and configure:

```
[mcu]                 # serial path from 3.5
[printer]             # kinematics: cartesian
[stepper_x]           # rotation_distance: 40, position_max: 235
[stepper_y]           # rotation_distance: 40, position_max: 235
[stepper_z]           # rotation_distance: 8, position_max: 250
[virtual_sdcard]
[pause_resume]
[display_status]
```

**[VERIFY]** rotation_distance values against the actual machine — CR-6 SE uses 20-tooth
GT2 pulleys (40 mm/rev) and a T8 lead screw (8 mm/rev), but confirm empirically in 4.3.

Start with **conservative** `max_velocity` / `max_accel`. Tuning comes in Phase 11.

## 4.2 [HUMAN] Test with your hand on the power switch

First `G28 X` and `G28 Y`, one axis at a time, ready to cut power if anything drives into
a hard stop.

## 4.3 [CC + HUMAN] Verify dimensional accuracy

Command a 100 mm X move. **[HUMAN]** measures actual travel with calipers or a steel rule.
Repeat for Y. Adjust `rotation_distance` proportionally if off. Get this right now — every
drawing you ever make inherits this error.

## 4.4 The Z homing problem

**The CR-6 SE has no mechanical Z endstop.** Stock, it homes Z using the strain gauge in
the toolhead bracket. We are not using the strain gauge, so Z needs a plan. Pick one:

**Option A — Mechanical switch (recommended, most bulletproof).**
Mount a microswitch to the frame so the X gantry trips it near the bottom of travel. Wire
to a free input identified in 1.1. Set as a normal `endstop_pin` in `[stepper_z]`. Set
once, correct forever, zero per-session ritual.

**Option B — Software Z reference (zero hardware, recommended if no free input).**
Skip Z homing entirely. At the start of each session:
1. Jog Z by eye until the pen is just clear of the paper
2. `SET_KINEMATIC_POSITION Z=5`
3. `G28 X Y`

Wrap this in a `PLOT_HOME` macro so it's one click. Costs you a 20-second ritual per
session. Because Z travel on a plotter is only a few millimetres, the loss of absolute Z
reference genuinely doesn't matter.

**Option C — Re-enable the strain gauge as a Z endstop only.**
The wiring already exists and the bracket is still the load cell. This is available if A
and B both annoy you, but it's the least-documented path and it's why we routed around it
in the first place.

**Done when:** all three axes move accurately and repeatably, and Z has a homing story.

---

# PHASE 5 — Strip the toolhead

Now, and not before now.

## 5.1 [HUMAN] Before you unplug anything

**Photograph every connector from multiple angles.** You will not remember which
2-pin plug went where.

**Trace the X endstop wiring first.** On some CR-6 SE units, toolhead-adjacent wiring runs
through the same loom. If you pull the loom and lose X homing, you've created a new problem.
Confirm X and Y endstops still work (`G28 X`, `G28 Y`) after every removal step.

## 5.2 [HUMAN] Remove

Power off and unplug from mains first. Remove:

- Hotend heater cartridge
- Thermistor
- Heatsink and heatbreak
- Hotend cooling fan
- Part cooling fan and duct
- Nozzle and heater block
- Extruder motor and Bowden/direct assembly
- Any plastic shroud that doesn't hold the bracket together

**Keep:**
- The **toolhead mounting bracket** — this is your pen mounting surface and it's also the
  strain-gauge load cell if you ever want Option C
- X carriage, wheels, belt, and belt tensioners
- X and Y endstops and their wiring
- All motion hardware

**Tidy the loom.** You've removed most of the wires in it. Cut it down, re-sleeve, and
strain-relieve it. Slack cable that snags mid-plot ruins the drawing.

## 5.3 [CC] Confirm nothing broke

`FIRMWARE_RESTART`, then re-run the Phase 4 tests. All three axes should behave identically
to before the strip. If Klipper now complains about a missing component, something is still
referenced in `printer.cfg` that shouldn't be.

**Done when:** the toolhead is bare, and X/Y/Z motion and homing are unchanged.

---

# PHASE 6 — Mount pen and servo

## 6.1 The pen holder design loop

Don't download someone else's holder. The CR-6 toolhead bracket isn't an Ender 3 bracket,
you have printers available, and a parametric design lets you tune the two things that
actually determine plot quality — rigidity and spring rate — instead of accepting a
stranger's guesses.

### 6.1a [HUMAN] Measure the bare bracket

With the toolhead stripped (Phase 5 complete), measure and record:

- Mounting hole spacing, X and Y, centre to centre
- Hole diameter
- Bracket face dimensions and any obstructions (screw heads, standoffs, belt clamp)
- **Distance from the bracket face to where the nozzle tip used to be**, in X, Y and Z
- Clearance behind the bracket for a servo body
- Belt path and X-carriage wheels — the holder must not foul either at full travel

Photograph with a rule in frame. Hand measurements and photos to [CC].

### 6.1b [CC] Generate a parametric OpenSCAD holder

Build `holder.scad` with everything above as named variables at the top of the file, plus:

```
pen_diameter        // barrel OD at the grip point
collet_wall         // sleeve thickness
spring_travel       // 3–5 mm
spring_od, spring_free_length
servo_arm_height    // where the lifter finger engages
tip_offset_x, tip_offset_y   // relative to old nozzle position
```

Emit both the holder body and a **collet** — a printed sleeve that adapts one pen barrel to
the holder's fixed bore.

**Design the collets so every pen's *tip* lands at the same Z when seated**, not so every
barrel seats at the same depth. Pens vary in tip-to-shoulder distance, so referencing off
the barrel means re-measuring `PEN_Z` on every swap. Referencing off the tip makes `PEN_Z`
a function of paper stock only — which is the whole point of section 7.4.

Print a collet per pen you own. This is the payoff for having spare printers: a $0 sleeve
per pen instead of a compromise clamp that half-fits everything.

### 6.1c [HUMAN + CC] Iterate

Four passes, roughly:

| Rev | Goal | What to check |
|---|---|---|
| v1 | Mount fit only — no pen bore, no spring | Bolts up flush, no rocking, clears belt and wheels at full X travel |
| v2 | Add pen bore and collet | Pen vertical in both axes (small square), no rotation, tip lands near old nozzle position |
| v3 | Add sprung travel | 3–5 mm, smooth, returns freely under its own spring, no binding |
| v4 | Add servo interface | Lifter finger engages cleanly, no side load on the carriage |

**The rigidity test that matters:** push sideways on the seated pen tip with a finger.
Any perceptible flex in the *mount* will show up as wandering lines. Compliance belongs
in the sprung travel and nowhere else. If v1 flexes, thicken it and reprint — this is a
20-minute fix now and an unfixable annoyance later.

Spring rate: a ballpoint pen's own spring is roughly right as a starting point. Too stiff
tears paper and fights the servo; too soft won't hold the pen down through direction
changes.

### 6.1d [HUMAN] Final mount

Bolt on the winning revision. Record the final `tip_offset_x` / `tip_offset_y` — these go
into the vpype profile in 9.2.

**Install a BIC Cristal.** Not a Micron. Not yet.

## 6.2 [HUMAN] Mount the servo

Mount the SG90 so its arm lifts the sprung pen carriage. Aim for roughly 4–5 mm of lift —
enough to clear the paper and any ink already laid down, not so much that lifts get slow.

Wire: signal to the free header pin from 1.1, plus 5V and GND.

**If the servo browns out or the board resets when it moves**, its stall current is too
much for the board's 5V rail. Power the servo from the Pi's 5V or a separate BEC instead,
**keeping ground common with the mainboard.** A servo on a separate supply with a floating
ground will behave erratically in ways that look like a software bug.

## 6.3 [CC] Add the servo to Klipper

```
[servo pen]
pin: <pin from 1.1>
minimum_pulse_width: 0.0005      # tune
maximum_pulse_width: 0.0025      # tune
initial_angle: <pen up angle>
```

**Use a mainboard pin, not a Pi GPIO.** Klipper schedules mainboard servo commands on the
same timeline as motion, so pen-up lands exactly where the toolpath says. A Pi GPIO servo
is outside the motion queue and will lag unpredictably — you'll get little ink tails on
every lift.

## 6.4 [CC] Find the angles, [HUMAN] eyeballs it

Iteratively `SET_SERVO SERVO=pen ANGLE=...` until you find clean up and down positions.
Record both. **Down should let the spring do the work** — the servo arm should release the
carriage, not press it into the paper.

**Done when:** `SET_SERVO` reliably lifts and drops the pen, with no board resets.

---

# PHASE 7 — Z reference and the one-time bed mesh

The bed on this machine is never coming off and never getting heated. Measure it once,
save it, never think about it again.

## 7.1 [CC] Add manual bed mesh

```
[bed_mesh]
speed: 60
horizontal_move_z: 5
mesh_min: 20, 20
mesh_max: 215, 215
probe_count: 5, 5
```

With no probe defined, Klipper uses the manual method.

## 7.2 [HUMAN] Run the mesh

`BED_MESH_CALIBRATE METHOD=manual`

At each of the 25 points, jog Z until a sheet of paper under the pen has slight drag, then
`ACCEPT`. Klipper walks you through the grid.

This takes 15 minutes and it is the last time you will do it.

## 7.3 [CC] Save it

`SAVE_CONFIG`. Commit the resulting `printer.cfg` to git immediately.

## 7.4 [CC] Establish the pen-down Z offset

Define a `PEN_Z` variable — the Z height at which the pen contacts paper with the spring
lightly compressed. One number per paper stock. Bristol and copy paper differ by a few
tenths; you'll adjust this occasionally and nothing else.

**Done when:** the mesh is saved, and a pen dragged across the full bed at `PEN_Z` makes
consistent contact everywhere.

---

# PHASE 8 — Macros

## 8.1 [CC] Write the core macros

In a separate `macros.cfg`, included from `printer.cfg`:

| Macro | Does |
|---|---|
| `PEN_UP` | Servo to up angle, short dwell so the move completes before travel |
| `PEN_DOWN` | Servo to down angle, short dwell |
| `PLOT_START` | Pen up, home, move to origin, enable mesh |
| `PLOT_END` | Pen up, Z clear, move head to front-left so paper is reachable, motors off |
| `PLOT_PAUSE` | Pen up, park, hold — for pen swaps mid-plot |
| `PLOT_RESUME` | Pen down at the exact previous position, continue |

Dwell times matter. A servo takes ~100–300 ms to travel. Too short and you draw during the
lift; too long and it's added to every single line segment in the drawing.

## 8.2 [CC] Multi-colour support

`PLOT_PAUSE` / `PLOT_RESUME` is what makes multi-pen work possible: plot layer 1, pause,
human swaps the pen, resume. vpype separates layers by SVG colour, so this maps cleanly.

**Done when:** macros work individually and `PLOT_START` → draw a square → `PLOT_END`
completes without intervention.

---

# PHASE 9 — The software pipeline

## 9.1 [CC] Install vpype

Install with `pipx` to keep it isolated. Add plugins:
- `vpype-gcode` — G-code output (required)
- `hatched` — image → hatched line art
- `vpype-flow-imager` — image → flow-field art
- `vpype-vectrace` — raster tracing

**[VERIFY]** current plugin names and whether text/Hershey font support is built into
vpype core or requires a plugin.

## 9.2 [CC] Write the vpype-gcode profile

A TOML profile that emits:
- `PEN_UP` before every travel move
- `PEN_DOWN` before every draw move
- `PLOT_START` at the top, `PLOT_END` at the bottom
- Correct units and the XY offset measured in 6.1

## 9.3 [CC] Build a `plot` CLI wrapper

One command from SVG to plotted. It should:

1. **Read** the SVG
2. **Scale and layout** to a named paper size, with margin
3. **Optimise** — this is where the time savings live:
   - `linemerge` — join paths whose endpoints nearly touch
   - `linesort` — reorder to minimise pen-up travel (frequently halves plot time)
   - `reloop` — randomise closed-path start points so loop seams aren't all aligned
   - `linesimplify` — drop redundant points
4. **Write** G-code via the profile
5. **Preview** — render the G-code to PNG, draw moves in one colour and travel moves in
   another. *Always look at this before plotting.*
6. **Estimate** plot time
7. **Upload** to Moonraker and optionally start

## 9.4 [CC] Build a dry-run mode

A flag that runs the full job with the pen forced up and Z raised 20 mm. Catches
out-of-bounds moves, mirrored output, and wrong scaling without wasting paper or a pen tip.

**Make this the default for any new file.** The cost is a few minutes; the alternative is
discovering the problem via a pen dragged off the edge of the bed.

## 9.5 [CC] Source-specific front ends

Each of these just needs to produce SVG, after which the pipeline above is identical:

- **Generative art** — Python (`vsketch`, `shapely`, `numpy`) → SVG
- **Handwriting / cards** — Hershey stroke fonts. These are *single-stroke* fonts designed
  for plotters; regular TTF outlines will plot as hollow outlined letters, which is almost
  never what you want.
- **Technical drawings** — DXF imports directly into vpype
- **Photos** — `hatched` or `vpype-flow-imager`

**Done when:** `plot drawing.svg --dry-run` completes a full pen-up pass with a correct
preview image.

---

# PHASE 10 — First real plot

## 10.1 [HUMAN] Set up paper registration

Glue or tape the printed corner blocks to the bed so paper lands in the same place every
time. On a dedicated machine this is worth doing permanently — it turns paper alignment
from a per-plot fiddle into dropping a sheet into a corner.

Record the paper origin in the vpype profile.

## 10.2 [HUMAN] Tape down a sheet of cheap paper. Install a BIC.

## 10.3 [CC] Plot a calibration sheet

Generate and plot a test page containing:
- A 100 × 100 mm square (dimensional check)
- Concentric circles (backlash and belt tension check)
- Parallel lines at 1 / 2 / 5 mm spacing (registration check)
- A diagonal grid (skew check)
- A short text string (font pipeline check)

## 10.4 [HUMAN + CC] Read the results

| Symptom | Cause | Fix |
|---|---|---|
| Square isn't square | Skew — frame not trammed | Square the gantry mechanically |
| Dimensions off | `rotation_distance` | Back to 4.3 |
| Circles have flat spots / corners overshoot | Acceleration too high | Reduce `max_accel` |
| Lines don't close — small gap at the end | Backlash | Tighten belts, check eccentric nuts |
| Ink tails at the start of lines | Pen-down dwell too short | Increase dwell in `PEN_DOWN` |
| Faint or skipping lines | Pen pressure / `PEN_Z` too high | Lower `PEN_Z` in small steps |
| Torn paper, pen digging | `PEN_Z` too low or spring too stiff | Raise `PEN_Z`, lighter spring |
| Wobbly lines at speed | Resonance | Reduce accel; consider input shaper |

Iterate here until the calibration sheet is clean. **Only then install a Micron.**

**Done when:** the calibration sheet is dimensionally accurate and visually clean.

---

# PHASE 11 — Tune for speed

You removed most of the toolhead mass. The stock motion limits are now absurdly
conservative — they were sized for a heavy hotend flinging molten plastic.

## 11.1 [CC] Raise limits incrementally

Increase `max_accel` in steps, re-plotting the calibration sheet each time, until line
quality degrades. Then back off 30%.

Expect to land somewhere well above print settings. Print acceleration was likely ~500
mm/s²; a bare pen carriage should tolerate several times that. Let the calibration sheet
tell you where the wall is rather than trusting any specific number.

## 11.2 Per-pen speed profiles

**Different pens have different maximum speeds, limited by ink flow, not motion.**

- Ballpoints tolerate high speed but may skip on fast direction changes
- Fineliners starve above a certain feedrate and produce faint lines
- Gel pens are the slowest and smear if you travel over wet ink

Store a speed profile per pen type in the `plot` tool and select it with a flag.

## 11.3 [CC] Input shaper (optional)

Klipper's input shaper meaningfully improves line quality at speed. It's normally tuned
with an accelerometer, but `SHAPER_CALIBRATE` with a plotted ringing-test pattern works
visually and costs nothing but paper.

## 11.4 Ink-drying awareness

For dense drawings, `linesort` may route the pen back over wet ink. If you get smearing,
constrain sort order or split into layers with a pause between.

**Done when:** plots are fast enough that you don't avoid starting them.

---

# PHASE 12 — Custom plotter UI *(defer this)*

**Do not start this until Phase 11 is done and you have plotted for a week or two.**

If you build a UI before you've used the machine, you will build the wrong one — you'll
guess at requirements and end up with the plotter equivalent of a temperature graph. Plot
first, notice what you keep doing by hand, then build *that*.

## 12.1 Scope

Mainsail is a general-purpose 3D printer UI, which is why it shows you empty temperature
panels and a missing extruder. A purpose-built plotter frontend would show:

- SVG in, with the G-code preview from 9.3 overlaid — draw moves vs travel moves
- Live progress drawn *onto* that preview as the plot runs
- `PEN_UP` / `PEN_DOWN` test buttons
- `PEN_Z` nudge, ±0.05 mm, live while the pen is down
- Pen profile picker that applies the speed limits from 11.2
- Layer list with pause-for-pen-swap
- Paper size and registration origin selector
- Job history with a thumbnail of each drawing

## 12.2 [CC] Build it

A Vue or React SPA talking to Moonraker's websocket, served by the nginx that KIAUH already
installed. The preview renderer from 9.3 is most of the hard part, already done.

**Build it responsive.** It then works on a phone at the machine, which is the only
"machine-side screen" this build needs.

## 12.3 Keep Mainsail installed

Two frontends against one Moonraker is fine and costs nothing. Mainsail becomes your
"is this my UI or is this Klipper?" oracle when something misbehaves. Do not remove it.

## 12.4 What *not* to build

**Do not reimplement Moonraker.** The API surface is the easy part; the job queue, print
state machine, file management, websocket subscription model, and job history underneath
it are not. You would spend real effort to arrive at an API that isn't better, only yours.
Claude Code doesn't need a nicer API than Moonraker — it needs *an* API, and that already
exists.

**Do not add a GPIO touchscreen.** A 3.5" SPI panel costs an evening of driver work
minimum, occupies the GPIO header, risks a proprietary-controller dead end, and leaves you
maintaining a second UI codebase at 480×320. Your phone running the responsive UI from 12.2
is strictly better in every dimension — resolution, framerate, and effort. The usual
argument for a machine-mounted screen assumes unattended eight-hour jobs; plots run twenty
minutes and you'll be standing there anyway.

*(Revisit only if, months in, reaching for your phone is a genuine annoyance. At that point
the UI already exists and the job shrinks to "make it work at 480×320.")*

---

**[CC] can own:** Klipper/Moonraker/Mainsail install, firmware build, all config and
macros, the vpype pipeline, the `plot` CLI, preview rendering, G-code inspection, log
reading, git hygiene, generative SVG scripts.

**[CC] cannot do, and should say so rather than guess:** identify the board revision from
memory, judge pen contact pressure, tram the gantry, decide when a line "looks right",
confirm a servo physically moved. Anything in this category, ask [HUMAN] to look.

**[HUMAN] should escalate to [CC]:** any error text (paste it verbatim, in full), any
"it moved wrong" (describe *what* it did, not what you think caused it), any config change
you're tempted to make by hand — let [CC] make it so it's in git.

---

# Appendix B — Failure modes ranked by likelihood

*(The usual #1 — "didn't print the parts before removing the hotend" — doesn't apply to
this build. Other printers are available.)*

1. **Pen mount flexes.** Every line is slightly wrong in a way that's maddening to
   diagnose, because nothing in software is causing it. Rigidity in the *mount*,
   compliance only in the sprung *travel*. Catch it at v1 in 6.1c.
2. **SD card won't flash.** Wrong format, wrong size, or a reused filename. See 3.2/3.3.
3. **Collets referenced off the barrel instead of the tip.** Every pen swap becomes a
   re-measurement. See 6.1b.
4. **Servo browns out the board.** Looks exactly like random firmware crashes. See 6.2.
5. **Gave up after the third smeared line.** The tuning table in 10.4 exists so you don't
   have to guess. Every one of these is a known, solved problem.

---

# Appendix C — First session checklist

Once built, a normal plotting session is:

1. Power on printer and Pi
2. `PLOT_HOME` (or `G28` if you fitted a Z switch)
3. Drop paper into the registration corners, tape
4. Install pen, confirm `PEN_Z` matches paper stock
5. `plot artwork.svg --dry-run`
6. Look at the preview image
7. `plot artwork.svg`
8. `PLOT_END`, remove paper, let ink dry before stacking

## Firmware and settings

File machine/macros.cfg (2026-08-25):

# ============================================================
# Plotter macros
#
# Z0 IS THE WRITING HEIGHT AND THE ABSOLUTE FLOOR.
# stepper_z position_min is 0, so once zeroed the machine physically
# cannot command the pen lower. PEN_DOWN goes to Z0 and no further.
#
# Session ritual:
#   1. PLOT_HOME              homes X/Y, clears the old origin
#   2. jog to one corner of the paper   -> PLOT_P1
#   3. jog to the OPPOSITE corner       -> PLOT_P2
#      (sets origin to the paper CENTRE and records the sheet size)
#   4. ZROOM, then jog down with ZDOWN until the pen is writing, with
#      the carriage floating off its stop
#   5. PLOT_ZERO_HERE         locks that as Z0, the floor
#   -> ready to plot
#
# The carriage is GRAVITY LOADED. Pen force is the weight of the moving
# assembly. Change the line weight by adding or removing mass, never by
# driving Z lower - it cannot go lower.
# ============================================================

[gcode_macro _PLOT_VARS]
# Set to 1 by PLOT_ZERO_HERE. Pen moves refuse until then.
variable_zeroed:       0
# Travel height above the writing height, in mm.
variable_lift:        10.0
# Measured carriage float, mm (owner: 0.6278 in). Reference only.
variable_max_float:   15.9
# Paper size in mm, filled in by PLOT_P2.
variable_paper_w:      0.0
variable_paper_h:      0.0
variable_z_up_feed:   1800
variable_z_down_feed:  900
variable_travel_feed:  9000
gcode:

[gcode_macro PEN_DOWN]
gcode:
    {% set v = printer["gcode_macro _PLOT_VARS"] %}
    {% if v.zeroed|int != 1 or "z" not in printer.toolhead.homed_axes %}
        RESPOND MSG="REFUSED: Z reference is not valid (zeroed={v.zeroed}, homed={printer.toolhead.homed_axes}). Re-run PLOT_ZERO_HERE at the writing height."
    {% else %}
        G90
        G1 Z0 F{v.z_down_feed}
    {% endif %}

[gcode_macro PEN_UP]
gcode:
    {% set v = printer["gcode_macro _PLOT_VARS"] %}
    {% if v.zeroed|int != 1 or "z" not in printer.toolhead.homed_axes %}
        RESPOND MSG="REFUSED: Z reference is not valid (zeroed={v.zeroed}, homed={printer.toolhead.homed_axes}). Re-run PLOT_ZERO_HERE at the writing height."
    {% else %}
        G90
        G1 Z{v.lift} F{v.z_up_feed}
    {% endif %}

[gcode_macro PLOT_ZERO_HERE]
description: Call with the pen AT the writing height, carriage floating. Locks this as Z0, the absolute floor.
gcode:
    {% set v = printer["gcode_macro _PLOT_VARS"] %}
    SET_KINEMATIC_POSITION Z=0
    SET_GCODE_VARIABLE MACRO=_PLOT_VARS VARIABLE=zeroed VALUE=1
    RESPOND MSG="Z0 locked at the current height. This is now the lowest the pen can go. PEN_UP travels to Z{v.lift}."

[gcode_macro PLOT_UNZERO]
description: Clear the Z reference, to set it again after moving the pen or paper.
gcode:
    SET_GCODE_VARIABLE MACRO=_PLOT_VARS VARIABLE=zeroed VALUE=0
    RESPOND MSG="Z reference cleared. Pen moves refuse until PLOT_ZERO_HERE runs again."

[gcode_macro ZROOM]
description: Give Z room to jog down, before it has been zeroed.
gcode:
    {% set v = printer["gcode_macro _PLOT_VARS"] %}
    {% if v.zeroed|int == 1 %}
        RESPOND MSG="REFUSED: Z is already zeroed at the writing height. Run PLOT_UNZERO first if you really mean to go below it."
    {% else %}
        SET_KINEMATIC_POSITION Z=200
        RESPOND MSG="Z re-declared as 200. Jog down with ZDOWN."
    {% endif %}

[gcode_macro ZDOWN]
description: Jog Z down. ZDOWN D=1 moves 1mm toward the paper.
gcode:
    {% set d = params.D|default(1)|float %}
    G91
    G1 Z-{d} F900
    G90
    RESPOND MSG="Z down {d} mm, now at {printer.toolhead.position.z|round(2)}"

[gcode_macro ZUP]
description: Jog Z up. ZUP D=1 moves 1mm away from the paper.
gcode:
    {% set d = params.D|default(1)|float %}
    G91
    G1 Z{d} F900
    G90
    RESPOND MSG="Z up {d} mm, now at {printer.toolhead.position.z|round(2)}"

[gcode_macro JOG]
description: Relative XY jog. JOG X=10 Y=-5
gcode:
    {% set x = params.X|default(0)|float %}
    {% set y = params.Y|default(0)|float %}
    G91
    G1 X{x} Y{y} F6000
    G90
    RESPOND MSG="now at X{printer.toolhead.position.x|round(1)} Y{printer.toolhead.position.y|round(1)}"

[gcode_macro GOTO]
description: Absolute XY move. GOTO X=110 Y=110
gcode:
    {% set x = params.X|default(printer.toolhead.position.x)|float %}
    {% set y = params.Y|default(printer.toolhead.position.y)|float %}
    G90
    G1 X{x} Y{y} F6000
    RESPOND MSG="now at X{x|round(1)} Y{y|round(1)}"

[gcode_macro PLOT_HOME]
description: Step 1. Home X/Y and clear any previous paper origin.
gcode:
    SET_GCODE_OFFSET X=0 Y=0
    G28 X Y
    RESPOND MSG="Homed. Jog to one corner of the paper, then run PLOT_P1."

[gcode_macro PLOT_P1]
description: Step 2. Call with the pen over ONE corner of the paper.
variable_x: 0.0
variable_y: 0.0
gcode:
    {% set p = printer.toolhead.position %}
    SET_GCODE_OFFSET X=0 Y=0
    SET_GCODE_VARIABLE MACRO=PLOT_P1 VARIABLE=x VALUE={p.x}
    SET_GCODE_VARIABLE MACRO=PLOT_P1 VARIABLE=y VALUE={p.y}
    RESPOND MSG="Corner 1 at X{p.x|round(1)} Y{p.y|round(1)}. Now jog to the OPPOSITE corner and run PLOT_P2."

[gcode_macro PLOT_P2]
description: Step 3. Call at the opposite corner. Sets centre origin and paper size.
gcode:
    {% set p = printer.toolhead.position %}
    {% set c1 = printer["gcode_macro PLOT_P1"] %}
    {% set w = (p.x - c1.x)|abs %}
    {% set h = (p.y - c1.y)|abs %}
    {% set cx = (p.x + c1.x) / 2.0 %}
    {% set cy = (p.y + c1.y) / 2.0 %}
    {% if w < 10 or h < 10 %}
        RESPOND MSG="Refused: that is only {w|round(1)} x {h|round(1)} mm. Did you move to the opposite corner?"
    {% else %}
        SET_GCODE_OFFSET X={cx} Y={cy}
        SET_GCODE_VARIABLE MACRO=_PLOT_VARS VARIABLE=paper_w VALUE={w}
        SET_GCODE_VARIABLE MACRO=_PLOT_VARS VARIABLE=paper_h VALUE={h}
        RESPOND MSG="Paper {w|round(1)} x {h|round(1)} mm, centre at machine X{cx|round(1)} Y{cy|round(1)}. Next: ZROOM, jog down with ZDOWN to the writing height, then PLOT_ZERO_HERE."
    {% endif %}

[gcode_macro PLOT_CENTER]
description: Quick alternative to P1/P2. Call with the pen at the middle of the sheet.
gcode:
    {% set p = printer.toolhead.position %}
    SET_GCODE_OFFSET X={p.x} Y={p.y}
    RESPOND MSG="Centre set at machine X{p.x|round(1)} Y{p.y|round(1)}. Paper size unknown, so pass --size WxH to plot."

[gcode_macro PLOT_START]
gcode:
    G90
    G21
    PEN_UP

[gcode_macro PLOT_END]
gcode:
    {% set v = printer["gcode_macro _PLOT_VARS"] %}
    PEN_UP
    G1 Z{v.lift + 15} F{v.z_up_feed}
    # park in MACHINE terms: the active gcode offset (paper centre) must be
    # subtracted, or this asks for a Y beyond the end of the rail
    G1 Y{printer.toolhead.axis_maximum.y - 15 - printer.gcode_move.homing_origin.y} F{v.travel_feed}
    # NO M84. Dropping the steppers erases the hand-set Z reference, which
    # would mean re-zeroing after every single plot. Motors stay energised.
    RESPOND MSG="Plot complete. Z reference retained - plot again without re-zeroing."

[gcode_macro PEN_CHANGE]
description: Between colour layers. Lifts, drops the Z reference, and pauses for a pen swap.
gcode:
    {% set v = printer["gcode_macro _PLOT_VARS"] %}
    {% set pen = params.PEN|default("the next pen") %}
    {% set i = params.INDEX|default(0)|int %}
    {% set n = params.OF|default(0)|int %}
    PEN_UP
    # Clear of the paper so the pen can be pulled out. Relative, because Z0 is
    # wherever this pen happened to write, not a fixed height.
    G91
    G1 Z20 F{v.z_up_feed}
    G90
    M400
    # The next pen is a different length, so the old Z0 is meaningless. Only the
    # FLAG is cleared here, never SET_KINEMATIC_POSITION: the pause captures the
    # current position, and redefining the frame before RESUME would send the
    # head back to a stale height. Unzeroed, PEN_DOWN refuses, so nothing can
    # draw until the new Z0 is locked by hand.
    PLOT_UNZERO
    RESPOND MSG="PEN CHANGE {i} of {n}: load {pen}. Then ZROOM, jog down with ZDOWN until it writes with the carriage floating, PLOT_ZERO_HERE, then RESUME."
    PAUSE

[gcode_macro PLOT_PAUSE]
gcode:
    PEN_UP
    PAUSE
    RESPOND MSG="Paused for pen swap. PLOT_RESUME when ready."

[gcode_macro PLOT_RESUME]
gcode:
    RESUME
    PEN_DOWN

[gcode_macro PEN_TEST]
description: Draw a 40mm square centred on the origin. Run the ritual first.
gcode:
    {% set v = printer["gcode_macro _PLOT_VARS"] %}
    {% if v.zeroed|int != 1 %}
        RESPOND MSG="REFUSED: no Z reference set. Run PLOT_ZERO_HERE first."
    {% else %}
        PEN_UP
        G1 X-20 Y-20 F{v.travel_feed}
        PEN_DOWN
        G1 X20 Y-20 F3000
        G1 X20 Y20 F3000
        G1 X-20 Y20 F3000
        G1 X-20 Y-20 F3000
        PEN_UP
        G1 X0 Y0 F{v.travel_feed}
    {% endif %}
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

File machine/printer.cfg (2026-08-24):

# ============================================================
# CR-6 SE  ->  PEN PLOTTER
# Board: Creality v4.5.2  (STM32F103, 28KiB bootloader, USART1 PA10/PA9)
# Derived from Klipper's shipped printer-creality-cr6se-2020.cfg,
# with every heater, thermistor and fan section deleted on purpose.
#
# Mainsail will show empty temperature graphs and no extruder panel.
# That is expected. Nothing is broken.
# ============================================================

[include macros.cfg]

# ---------- MCU ----------
# TODO: replace with the real path from `ls /dev/serial/by-id/` after flashing.
[mcu]
serial: /dev/serial/by-id/usb-1a86_USB_Serial-if00-port0
restart_method: command

# ---------- Motion ----------
[printer]
kinematics: cartesian
max_velocity: 500
max_accel: 500          # deliberately conservative; raise in Phase 11
max_z_velocity: 5
max_z_accel: 100

[stepper_x]
step_pin: PB8
dir_pin: !PB7
enable_pin: !PC3
rotation_distance: 40   # VERIFY empirically in Phase 4.3
microsteps: 16
endstop_pin: PC4
position_min: -5
position_endstop: -5
position_max: 235
homing_speed: 50

[stepper_y]
step_pin: PB6
dir_pin: PB5
enable_pin: !PC3
rotation_distance: 40   # VERIFY empirically in Phase 4.3
microsteps: 16
endstop_pin: PC5
position_min: -2
position_endstop: -2
position_max: 235
homing_speed: 50

[stepper_z]
step_pin: PB4
dir_pin: !PB3
enable_pin: !PC3
rotation_distance: 8
microsteps: 16
# ---- Z HOMING: see Phase 4.4. Stock CR-6 SE has NO mechanical Z endstop.
# Currently configured for OPTION B (software Z reference, zero hardware):
# no endstop at all; PLOT_HOME sets Z by eye each session.
# For OPTION A (mechanical switch, recommended), delete the two lines below,
# uncomment endstop_pin, and set position_endstop after fitting the switch.
#endstop_pin: ^PA7      # freed filament-sensor header - ideal Z endstop input
#position_endstop: 0
endstop_pin: PA4        # strain gauge; NOT used for homing, placeholder only
position_min: -1.5
position_max: 250
homing_speed: 4
second_homing_speed: 1
homing_retract_dist: 2.0

# ---------- Pen servo ----------
# PA6 was the stock LED output. It is free now and is the servo candidate.
# Angles are placeholders until Phase 6.4 finds them by eye.
[servo pen]
pin: PA6
minimum_pulse_width: 0.0005
maximum_pulse_width: 0.0025
initial_angle: 90

# ---------- Bed mesh (Phase 7, one-time manual) ----------
[bed_mesh]
speed: 60
horizontal_move_z: 5
mesh_min: 20, 20
mesh_max: 215, 215
probe_count: 5, 5

# ---------- Plumbing ----------
[virtual_sdcard]
path: ~/printer_data/gcodes

[pause_resume]
[display_status]
[respond]
[force_move]
enable_force_move: True   # needed for SET_KINEMATIC_POSITION in PLOT_HOME

[static_digital_output daughterboard_communication]
pins: !PA5

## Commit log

2026-08-24 CR-6 SE pen plotter: machine config, toolhead, tools, and the Windows app
    One repo for both halves of the project.
    - app/ Electron control app (Plotter.exe). SVG parse, flatten, transform,
    linemerge/linesort/reloop/simplify, layout, gcode, and PNG/JPG
    tracing, all in-process. Talks to plain Klipper + Moonraker.
    - machine/ printer.cfg, macros.cfg, the gravity-loaded pen toolhead (SCAD +
    STLs), Klipper firmware for the v4.5.2 board, the earlier vpype
    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
    [holder-bottom.stl, holder-carriage.stl, holder-sleeve.stl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]
2026-08-25 Add outline tracing mode for line art (#1)
    The centreline tracer fragments detailed line art (coloring-book pages,
    inked scenes) into a broken, sketchy skeleton. Add an outline mode that
    traces the boundary of the ink as closed contours instead, reproducing
    line art faithfully.
    - core/trace.js: outlineFromInk() walks the ink/paper boundary into
    closed loops (most-CCW turn at junctions). traceImage gains an
    `outline` option returning those loops with the same stats shape.
    - main.js: outline mode traces at native resolution (upscale forced to
    1; upsampling only helps the skeleton, not the boundary).
    - Default on (store traceOutline: true) with a toggle in the tracing
    panel; fills/hatc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
2026-08-25 Release 1.1.0 — outline tracing default
2026-08-25 Fix left panel not scrolling to the Send button (1.1.1)
    The Plot card's content (tracing options -> toggles -> Send / Save gcode)
    is taller than the panel. The cards are flex items in the column, so with
    default flex-shrink they squashed to fit and, because .card has
    overflow:hidden, clipped their own overflow -- the Send button vanished
    below the fold and the panel never reported anything to scroll.
    Pin the panel's cards/banners to their natural height (flex:0 0 auto) so
    the overflow lands on the panel, which then scrolls as intended.
2026-08-25 Multicolour: one pen per colour, with a pen-change pause (1.2.0)
    Separate a PNG into a small number of pen colours and plot each as its
    own layer, pausing between them to swap the pen.
    - core/colours.js: deterministic k-means in RGB (fixed LCG seed, so the
    palette never wobbles and the trace cache holds), near-white treated as
    paper, one mask per pen, ordered lightest first so dark ink lands last.
    - Each mask is outline-traced via trace.tracePathsFromMask and enters the
    pipeline as its own layer; buildLayers now reports stats.runs (where
    each layer's paths start) and carries the colour through.
    - toGcode drops PEN_CHANGE on each layer boundary and lists the pen order
    in the header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
    [macros.cfg]
2026-08-25 Sync machine/macros.cfg with the live plotter
    The repo copy had drifted behind the Pi: the machine has a 10mm lift (not
    2mm), faster Z feeds, and PEN_DOWN/PEN_UP guards that also check
    homed_axes. Take the running config as the truth, with PEN_CHANGE added.
    [macros.cfg]
2026-08-25 Fix: the pen-change pause had no way to re-zero (1.2.1)
    A paused plot still reports printing, and every Z control was gated on
    that -- so at a pen change the machine sat waiting for a new Z0 while the
    app had disabled Give Z room, the Z jog buttons and Lock Z0 here. The one
    thing the operator had to do was the one thing they could not do.
    - Gate those controls on actually moving (printing && !paused) instead of
    on having a job loaded. Home, Set corner, Pen test and Send stay locked
    while paused: they would wreck the job in progress.
    - Add a pen-change panel that appears on a pen-change pause, naming the
    pen from what PEN_CHANGE actually said, with the whole ritual in one
    place: Give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
